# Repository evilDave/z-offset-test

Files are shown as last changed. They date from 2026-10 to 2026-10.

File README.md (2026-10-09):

# z-offset-test

Model, Orca 3mf project and Python script for calibrating the z-offset on 3D printers.

## Files

- **`z-offset-test.py`** - Python script that detects the long and short line X values in sliced G-code and adds incremental Z-height adjustments for testing different z-offset values
- **`z-offset-test-model.step`** - 3D model with 16 test tabs: 5 closer, the current z-offset (rounded end), then 10 farther
- **`z-offset-test.3mf`** - Orca Slicer project file with pre-configured settings and post-processing script integration
- **`images/`** - Diagrams for the model geometry notes below

## How to Use

### Purpose
This tool helps calibrate the z-offset by automatically adding incremental Z-height adjustments to specific regions of your G-code. The model has 16 tabs so you can compare 5 steps closer to the bed, your current z-offset, and 10 steps farther away, all in one print. The current-offset tab is the one with a rounded end.

### Usage

#### Initial setup
Before running this test, set a rough z-offset so you are deliberately a little too close to the bed. The print then steps farther in 0.01mm increments, so starting slightly low keeps more of the useful range on the "too close" side of your current setting.

- **Klipper (probe):** Run [`PROBE_CALIBRATE`](https://www.klipper3d.org/Probe_Calibrate.html) (home first, then the command in the terminal or your front-end's calibration menu). Use the paper test at the end, but err on the tight side so the nozzle is slightly closer than you would normally leave it.
- **Klipper (Z endstop, no probe):** Same idea with [`Z_ENDSTOP_CALIBRATE`](https://www.klipper3d.org/Manual_Level.html#calibrating-a-z-endstop).
- **Other firmware / manual:** Use the paper method (or your printer's equivalent first-layer calibration). Again, pull the paper tighter than usual so you know you are a touch too close, then fine-tune with this test.

Regardless of method below, the test can be used like this:
1. Leave your current z-offset as-is once that rough setup is done (or if first layers were already roughly okay). The script starts 0.05mm closer to the bed than the sliced 0.2mm layer, then steps farther away by 0.01mm each tab.
2. Slice / process / print the model
3. Choose the best tab. Look for a flat surface with no tearing, but make sure you cannot see gaps in between the print lines. The rounded-end tab is your current z-offset (0.20mm); the five tabs before it are closer, the ten after it are farther. If several tabs look good, use the tradeoff in Tips below rather than defaulting to the middle one.
4. Modify your z-offset accordingly. Count from the rounded tab: each tab before it is 0.01mm closer to the bed, each tab after it is 0.01mm farther.
5. If every tab still looks too far from the bed (gaps between lines, no squish), your current z-offset is more than 0.05mm too high. Move it 0.05mm closer and run the test again.

#### Method 1: Orca Slicer Integration
1. Open `z-offset-test.3mf` in Orca Slicer
2. The project is pre-configured with the correct settings and post-processing script
3. Update the location of the script in the "others" tab of the process settings
4. Select your printer and filament, then slice the model and the script will automatically run when you generate the G-code

#### Method 2: Command Line
```bash
python3 z-offset-test.py <your_file.gcode>
```

### How it Works
1. The script starts processing after the `printing object` comment in the G-code (so travel and start G-code are ignored)
2. It collects the X coordinates at both ends of every extruding G1 move (travel moves are ignored, since with the Monotonic line pattern they stop near the line ends), then works out the long and short section X values automatically:
   - Unique X values are split at the midpoint between the leftmost and rightmost X
   - Only the right-hand boundary values (above that midpoint) are considered
   - The most frequent of those is the long line; the second most frequent is the short line
   - Those two values must differ by at least 5 mm
3. On a second pass, before the first tab and whenever a G1 move hits the short-line X (the gap before each later tab), the script inserts:
   - A Z-height adjustment (starting at 0.15 mm, 0.05 mm closer than the 0.2 mm layer, incrementing by 0.01 mm each time)
   - A beep command (M300) for audio feedback
4. A later G1 move that hits the long-line X, or any extruding move into the tab area, marks the end of that short section. The rounded tab's lines stop short of the long-line X, so the tab-area check is what catches it
5. This creates a 16-tab test pattern: 0.15–0.19mm (closer), 0.20mm (current, rounded-end tab), then 0.21–0.30mm (farther)

The determined long and short X values are written as comments at the top of the processed G-code.

The top of the processed G-code also says that it was modified by `z-offset-test.py`, links to this repo, and explains why. Every comment the script adds starts with `[z-offset-test.py]`, and each Z change is preceded by one, so searching the G-code for `[z-offset-test.py]` lists every height change.

If the script can't find the long and short lines, it exits with an error and leaves the G-code unchanged, so Orca shows the failure when exporting instead of silently skipping the test.

Orca only runs post-processing scripts when exporting or sending G-code. The slicer's preview always shows the unmodified G-code.

### Manual setup in slicer
These are the settings that are needed for the test script to work and for the print to show the differences of z-offset changes:
- Make sure your layer height is equal to the model height (so you get 1 layer only)
- Initial layer height: 0.2mm (the same as the layer height)
- Initial layer line width: 105% (0.42mm on a 0.4mm nozzle). The model's tab sizes are designed for this width
- Wall loops: 0
- Solid infill direction: 0
- Bottom surface pattern: Monotonic line. Plain Monotonic joins lines by running along the tab edges, which adds stray lines and gives the tabs inconsistent line counts
- Elephant foot compensation: 0. The model is a single layer, so compensation shrinks every tab and changes how many lines each tab gets
- Apply gap fill: Nowhere
- Post-processing Scripts: `[your file location]/z-offset-test/z-offset-test.py;`

### Model geometry
The model is sized so that Orca prints exactly 10 lines in every tab and 2 lines in every gap between tabs. This only works if the sizes are based on Orca's line spacing rather than the line width.

Orca models each line as a rectangle with rounded sides, so neighbouring lines overlap and are closer together than the line width. In the Onshape model the sizes come from these variables:

```text
#lineWidth   = #nozzle * 1.05                                  // 0.42 mm
#lineSpacing = #lineWidth - #layerHeight * (1 - PI / 4)        // 0.3771 mm
#edgeOffset  = #layerHeight * (1 - PI / 4)                     // 0.0429 mm
```

`#layerHeight` is the initial layer height (0.2mm), because the model is a single layer.

- Tab: `10 * #lineSpacing` (3.7708mm)
- Gap: `2 * #lineSpacing` (0.7542mm)
- Pitch: `12 * #lineSpacing` (4.5250mm). One tab and gap is sketched, extruded, then patterned 16 times, and the extra gap after the last tab is removed
- Total height: `190 * #lineSpacing + 2 * #edgeOffset + 0.05 mm` (71.781mm)

After patterning, two Move face (offset) operations are applied to the faces at each end of the pattern. Each face runs across the full width, covering the base and the end tab:

- Bottom face (start of the pattern): outwards by `#edgeOffset`
- Top face (end of the pattern): outwards by `#edgeOffset + 0.05 mm`

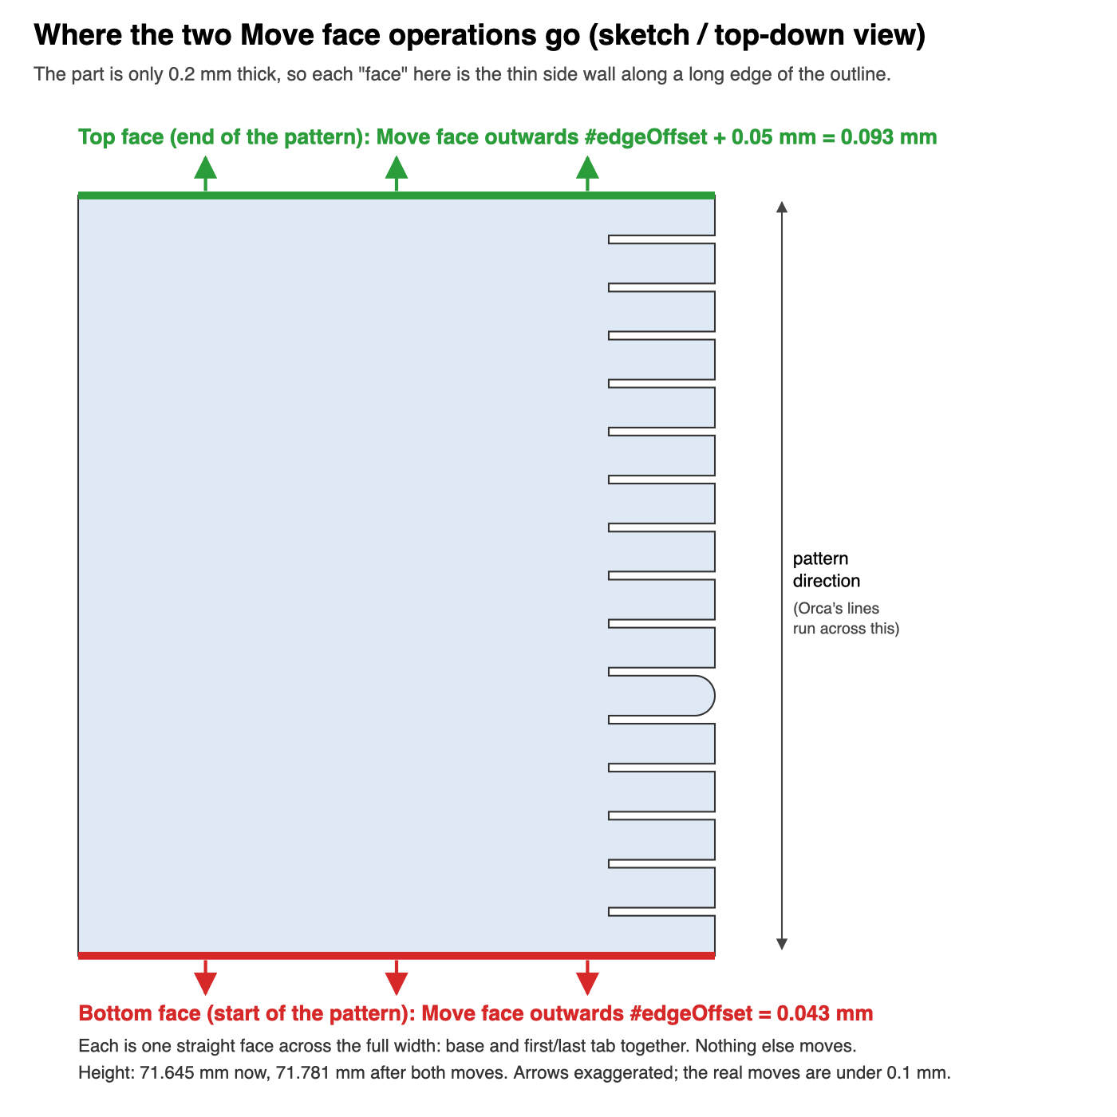
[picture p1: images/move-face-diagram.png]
Where the two Move face operations go


Why these are needed:
- Orca starts its lines `#edgeOffset` in from each outer edge. Without the offsets, the line grid doesn't line up with the tab and gap edges.
- Orca works out how many lines fit, rounds down, then stretches the spacing to fill the space. The stretch builds up along the part, and the middle tabs end up with 9 lines and gaps with 3. The extra 0.05mm on the top face keeps the space clearly above 190 lines (a 191st line would need another 0.377mm), so rounding never drops to 189.

If you change the nozzle size, line width percentage or initial layer height, update the variables and the same formulas still apply.

Sliced with the settings above, every tab gets 10 lines and every gap gets 2:

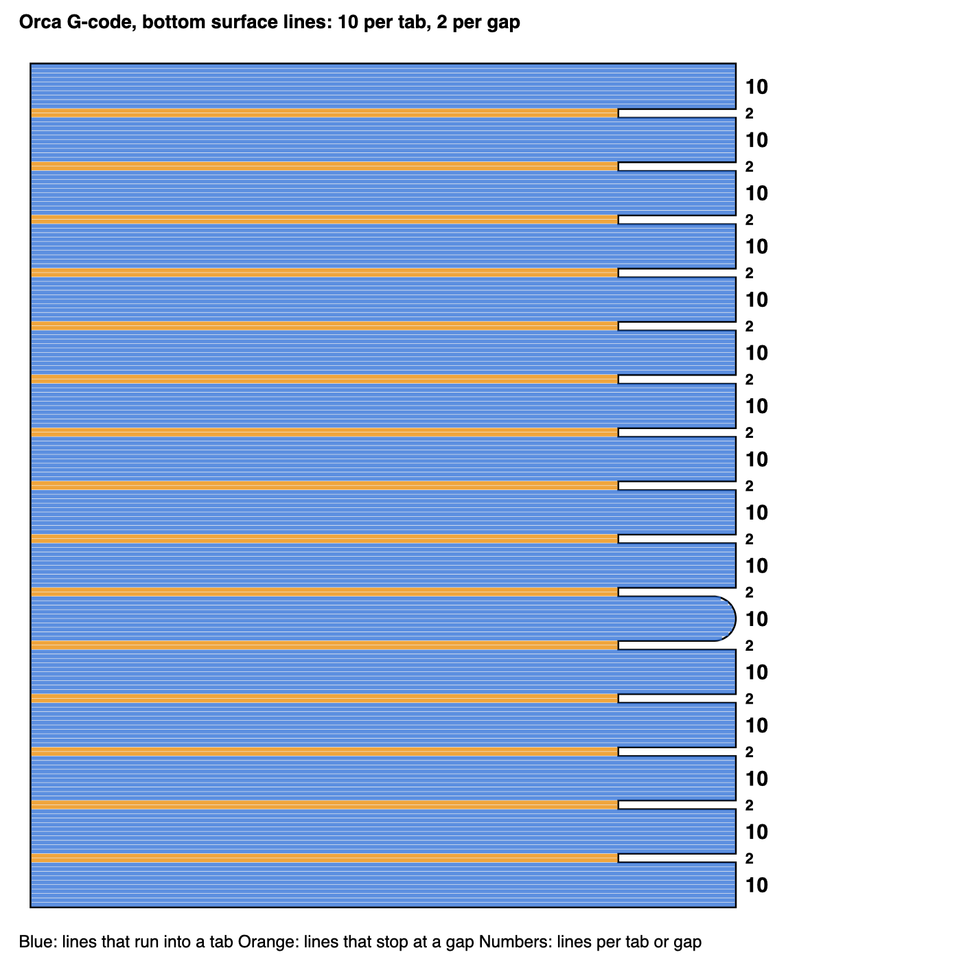
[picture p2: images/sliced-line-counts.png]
Orca G-code bottom surface lines: 10 per tab, 2 per gap


### Tips
- Check the sliced preview before printing: every tab should have 10 lines and every gap 2 (see the image above). If they differ, check the bottom surface pattern, elephant foot compensation and initial layer line width settings above
- Listen for the beeps to know when z-offset changes occur
- The first tab starts at 0.15mm (0.05mm closer than the 0.2mm layer) and increments by 0.01mm each time, through 0.30mm
- The rounded-end tab is the current z-offset (0.20mm). Count tabs from there rather than from the start of the print
- Look for a tab of correctly squished first layer, then adjust your z-offset by 0.01mm per tab away from the rounded one
- When more than one tab looks acceptable, it is a tradeoff: a little farther from the bed reduces elephant's foot and is often a good fit for PETG; a little closer improves bed adhesion, which helps with PLA. Pick where you want to sit on that balance
- If the whole print is still too far from the bed, move your z-offset 0.05mm closer and try again

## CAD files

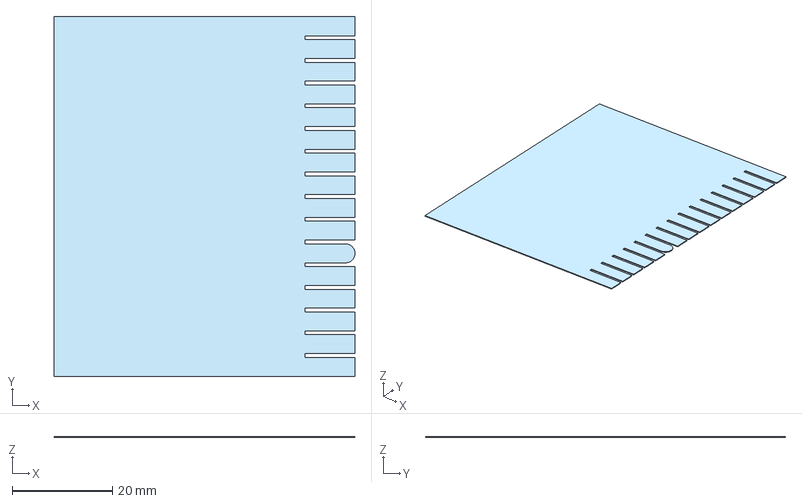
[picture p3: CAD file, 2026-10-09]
z-offset-test-model.step
60.0 x 71.8 x 0.2 mm

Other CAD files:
z-offset-test.3mf

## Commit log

2025-07-30 add model, project, and instructions
    [z-offset-test-model.step, z-offset-test.3mf]
2026-10-08 update model
    [z-offset-test.3mf]
2026-10-08 document auto-detected long/short line X and fix script usage
    [z-offset-test.3mf]
2026-10-09 start the test 0.05mm closer so an okay z-offset can be left as-is
2026-10-09 Expand to a 16-tab model with documented geometry and a more reliable post-processor.
    The script now keys off extruding moves only, handles the first and rounded-end tabs, tags G-code changes, and fails loudly when tab lines cannot be detected.
    [z-offset-test-model.step, z-offset-test.3mf]
2026-10-09 Document rough z-offset setup and material tradeoffs when picking a tab.
    Covers Klipper PROBE_CALIBRATE, a tight paper-method start, and PLA adhesion vs PETG elephant foot.
